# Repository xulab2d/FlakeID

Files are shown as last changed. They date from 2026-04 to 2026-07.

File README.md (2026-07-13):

# FlakeID

`flake-ml` is the starter software stack inside `FlakeID`, a research-backed framework for automated optical discovery of exfoliated 2D material flakes on a motorized microscope. It is designed around your current setup:

- Microscope: Zeiss AXIO Imager.A2m
- Motion: Arduino UNO + CNC shield running GRBL
- Camera: Canon DS126571 over USB
- Primary materials:
  - graphene on 285 nm Si/SiO2 (wet)
  - hBN on 90 nm Si/SiO2 (dry)

This repository focuses on the parts we can build immediately on the local workstation:

- serpentine scan planning
- GRBL integration hooks
- flat-field and background correction
- lightweight flake-candidate detection on CPU
- scan cataloging and COCO export for future training
- a practical data and human-in-the-loop plan

It also leaves clean interfaces for stronger models and remote training later.

## Repository Layout

- [docs/research_review.md](docs/research_review.md)
- [docs/system_architecture.md](docs/system_architecture.md)
- [docs/data_and_human_loop.md](docs/data_and_human_loop.md)
- [docs/bringup_checklist.md](docs/bringup_checklist.md)
- [docs/scanning_protocol.md](docs/scanning_protocol.md)
- [docs/stage_bounds_protocol.md](docs/stage_bounds_protocol.md)
- [docs/stage_calibration_ui.md](docs/stage_calibration_ui.md)
- [docs/camera_pathway.md](docs/camera_pathway.md)
- [docs/data_collection_workflow.md](docs/data_collection_workflow.md)
- [docs/drift_correction.md](docs/drift_correction.md)
- [docs/hardware_probe_notes.md](docs/hardware_probe_notes.md)
- [docs/repo_push_setup.md](docs/repo_push_setup.md)
- [configs/lab.example.toml](configs/lab.example.toml)
- [scripts/grbl_send.ps1](scripts/grbl_send.ps1)
- `src/flake_ml`: package code
- `tests`: lightweight regression tests

## Quick Start

Use the bundled Python runtime already available on this machine:

```powershell
& 'C:\Users\xulab\.cache\codex-runtimes\codex-primary-runtime\dependencies\python\python.exe' -m flake_ml.cli --help
```

Create a scan plan:

```powershell
& 'C:\Users\xulab\.cache\codex-runtimes\codex-primary-runtime\dependencies\python\python.exe' -m flake_ml.cli scan-plan `
  --config configs/lab.example.toml `
  --width-mm 8 `
  --height-mm 8 `
  --output outputs/scan_plan.json
```

Open the stage calibration UI:

```powershell
powershell.exe -NoProfile -ExecutionPolicy Bypass -File scripts\launch_stage_ui.ps1 `
  -Config configs/lab.example.toml
```

Run a capture scan over a saved scan ROI:

```powershell
& 'C:\Users\xulab\.cache\codex-runtimes\codex-primary-runtime\dependencies\python\python.exe' -m flake_ml.cli run-scan `
  --config configs/lab.example.toml `
  --sample-id graphene_grid_001 `
  --material graphene `
  --substrate graphene_285_wet `
  --objective 10x
```

Detect candidates in one image:

```powershell
& 'C:\Users\xulab\.cache\codex-runtimes\codex-primary-runtime\dependencies\python\python.exe' -m flake_ml.cli detect-image `
  path\to\image.jpg `
  --config configs/lab.example.toml `
  --output-json outputs\image_candidates.json `
  --overlay outputs\image_overlay.png
```

Probe the connected camera and installed Canon tooling:

```powershell
& 'C:\Users\xulab\.cache\codex-runtimes\codex-primary-runtime\dependencies\python\python.exe' -m flake_ml.cli camera-probe
```

Create a session scaffold for a new data-collection run:

```powershell
& 'C:\Users\xulab\.cache\codex-runtimes\codex-primary-runtime\dependencies\python\python.exe' -m flake_ml.cli init-session `
  --config configs/lab.example.toml `
  --output-root outputs\sessions `
  --sample-id graphene_trial_001 `
  --material graphene `
  --substrate graphene_285_wet `
  --objective 10x `
  --operator xulab
```

Estimate residual overlap shift between neighboring tiles:

```powershell
& 'C:\Users\xulab\.cache\codex-runtimes\codex-primary-runtime\dependencies\python\python.exe' -m flake_ml.cli estimate-shift `
  path\to\left_tile.jpg `
  path\to\right_tile.jpg `
  --axis x `
  --overlap-fraction 0.12
```

Score a z-stack or focus bracket with autofocus metrics:

```powershell
& 'C:\Users\xulab\.cache\codex-runtimes\codex-primary-runtime\dependencies\python\python.exe' -m flake_ml.cli focus-score `
  path\to\zminus.jpg `
  path\to\z0.jpg `
  path\to\zplus.jpg `
  --metric tenengrad `
  --crop-fraction 0.5
```

Replay a folder of microscope images into a catalog:

```powershell
& 'C:\Users\xulab\.cache\codex-runtimes\codex-primary-runtime\dependencies\python\python.exe' -m flake_ml.cli replay-folder `
  path\to\images `
  --config configs/lab.example.toml `
  --catalog outputs\flakes.db `
  --sample-id graphene_trial_001 `
  --material graphene
```

Export reviewed candidates to COCO:

```powershell
& 'C:\Users\xulab\.cache\codex-runtimes\codex-primary-runtime\dependencies\python\python.exe' -m flake_ml.cli export-coco `
  --catalog outputs\flakes.db `
  --output outputs\coco_candidates.json
```

Open the manual review UI for a scan session:

```powershell
& 'C:\Users\xulab\.cache\codex-runtimes\codex-primary-runtime\dependencies\python\python.exe' -m flake_ml.cli review-images `
  --session-dir photos\scans\20260424T024315Z_flake_grid_001
```

Launch the polygon-aware napari reviewer for precise flake boundaries:

```powershell
powershell.exe -NoProfile -ExecutionPolicy Bypass -File scripts\launch_napari_review.ps1 `
  -SessionDir photos\scans\20260424T024315Z_flake_grid_001
```

Use napari polygon mode for irregular flake outlines and rectangle mode only for quick coarse labels. The napari reviewer saves polygon vertices directly into the same `manual_annotations.json` file, so later COCO exports keep the real outline instead of collapsing everything to crude boxes.

Recommended tile labels:

- `flake_present`: the field contains one or more flakes worth annotating
- `empty_substrate`: true negative on the correct substrate with no flake present
- `off_target`: the stage is between sites or otherwise not over a useful survey location
- `bad_focus`: the field is not trustworthy because focus failed
- `artifact`: dust, glare, tape residue, edge effects, or other nuisance structure
- `unsure`: reviewer cannot confidently decide yet

Object labels stay flake-specific: `graphene`, `hbn`, `other_flake`, and `artifact`.

The napari reviewer also supports object-level metadata for downstream ranking:

- `thickness_bin`: `unknown`, `mono`, `bi`, `few_layer`, `thick`
- `size_class`: `unknown`, `tiny`, `small`, `usable`, `large`
- `shape_class`: `unknown`, `bottom_gate_candidate`, `channel_candidate`, `irregular`, `fragmented`
- `priority`: `unknown`, `ignore`, `review`, `device_candidate`

Set those in the dock and click `Apply Metadata To Selected` after selecting one or more flakes.

Reviewer navigation tips:

- reopening the same session resumes at the most recently saved image
- type an image number or filename fragment in the jump box and press `Enter`
- `[` and `]` move backward and forward
- `Ctrl+L` focuses the jump box
- `Ctrl+G` jumps to the typed image
- `Ctrl+J` jumps back to the saved resume target

Export manual review polygons or boxes to COCO:

```powershell
& 'C:\Users\xulab\.cache\codex-runtimes\codex-primary-runtime\dependencies\python\python.exe' -m flake_ml.cli export-manual-coco `
  --review-path photos\scans\20260424T024315Z_flake_grid_001\labels\manual_annotations.json `
  --output outputs\manual_annotations.coco.json
```

## Photo Storage

- `photos/incoming`: fallback hot folder for EOS Utility download handoff
- `photos/scans/<timestamp>_<sample_id>`: one folder per scan with tiles, logs, QC, and catalog files
- `photos/scans/<timestamp>_<sample_id>/labels/manual_annotations.json`: manual flake review output from the Tk reviewer or the napari polygon reviewer

The `photos/` tree is gitignored.

## Direct Canon Capture

The preferred camera path on this workstation is now the local Canon SDK helper:

```powershell
powershell.exe -NoProfile -ExecutionPolicy Bypass -File scripts\canon_sdk_capture.ps1 -Probe
```

For a direct still-image test:

```powershell
powershell.exe -NoProfile -ExecutionPolicy Bypass -File scripts\canon_sdk_capture.ps1 `
  -Output outputs\camera_test.jpg
```

Close `EOS Utility` or any Canon live-view window before using the direct SDK path, because the camera session is exclusive.

## What This Does Not Yet Solve

- autofocus for Z
- robust multilayer thickness regression
- remote model training orchestration
- scan-time stitch mosaics

Those are all outlined in the docs as the next build stages.

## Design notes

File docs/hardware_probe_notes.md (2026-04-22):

# Hardware Probe Notes

Date: `2026-04-22`

These notes were collected directly from the microscope control computer without moving the stage.

## GRBL Reachability

- `COM3` responds as `Grbl 0.9j`
- a status probe returned:
  - `<Idle,MPos:0.000,0.000,0.000,WPos:-1.050,-3.000,0.000>`

This means the Arduino/GRBL side is reachable from the workstation.

## Reported GRBL Settings

- `$100=250.000` x steps/mm
- `$101=250.000` y steps/mm
- `$102=250.000` z steps/mm
- `$110=200.000` x max rate mm/min
- `$111=500.000` y max rate mm/min
- `$112=500.000` z max rate mm/min
- `$120=10.000` x accel mm/s^2
- `$121=10.000` y accel mm/s^2
- `$122=10.000` z accel mm/s^2
- `$130=200.000` x max travel mm
- `$131=200.000` y max travel mm
- `$132=200.000` z max travel mm

## Immediate Implications

- GRBL coordinates are in `mm`, so the software layer should expose microns internally but convert to millimeters at the hardware boundary.
- The current default travel rate in the config, `2500 um/s`, corresponds to `150 mm/min`, which is under the current x-axis max rate of `200 mm/min`.
- Early scan tests should stay comfortably below the configured x-axis maximum until real motion is validated on the microscope.

## Recommended Next Hardware Test

1. Unlock GRBL if needed.
2. Jog `50 um` in `+X`, then return.
3. Jog `50 um` in `+Y`, then return.
4. Confirm the microscope image motion matches the expected axis signs.
5. Only then attempt a `3 x 3` image overlap test.

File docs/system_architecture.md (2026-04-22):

# System Architecture

## Goal

Turn a motorized optical microscope into a reliable flake-scanning instrument that can:

1. move reproducibly across a sample,
2. capture tiles with stable metadata,
3. detect likely flakes,
4. rank them for review or revisits,
5. accumulate training data for stronger models.

## Architecture

### 1. Motion Layer

Responsibilities:

- connect to GRBL on the Arduino UNO
- home and unlock safely
- move to absolute XY positions
- wait for idle before capture

Implementation in this repository:

- `flake_ml.motion.base.MotionController`
- `flake_ml.motion.grbl.PowerShellGrblController`
- `flake_ml.motion.pyserial_grbl.PySerialGrblController`
- `scripts/grbl_send.ps1`

Why this design:

- `pyserial` is not guaranteed on this machine, but PowerShell can access `System.IO.Ports.SerialPort` directly on Windows.
- The PowerShell path is useful for probing or one-off diagnostics.
- Real automated scanning should use the persistent `PySerialGrblController`, because reopening the serial port can reset an Arduino UNO running GRBL.

## 2. Camera Layer

Responsibilities:

- trigger a capture
- save the image to a known path
- attach tile metadata

Implementation in this repository:

- `flake_ml.acquisition.base.Camera`
- `flake_ml.acquisition.command.ExternalCommandCamera`
- `flake_ml.acquisition.command.DirectoryReplayCamera`

Why this design:

- Canon tethering is the least stable part of the current setup because the exact Windows-side control path is still unknown.
- An external command interface lets you plug in EOS Utility, Canon SDK tooling, `gphoto2`, or any future wrapper without touching the rest of the pipeline.

## 3. Scan Planner

Responsibilities:

- convert sample bounds and field of view into a tile grid
- use a serpentine path to reduce wasted stage travel
- preserve stage coordinates for every image

Implementation:

- `flake_ml.scanning.planner.build_serpentine_plan`

## 4. Preprocessing

Responsibilities:

- flat-field correction
- white-balance normalization
- slow-varying background estimation
- stable inputs for classical and learned detectors

Implementation:

- `flake_ml.processing.preprocess`

## 5. Detection

Responsibilities:

- generate conservative candidate regions from a tile
- score candidates for review
- compute features for later clustering or learning

Implementation:

- `flake_ml.detection.classical.ClassicalFlakeDetector`
- `flake_ml.detection.components`
- `flake_ml.processing.features`

Current algorithm:

- estimate background by downsampling and re-expanding the image
- measure robust color/saturation/luminance deviations
- build a candidate mask
- clean it with simple morphology
- run connected components
- compute component statistics
- assign heuristic scores

Why this first:

- It is fast on CPU.
- It gives you useful candidates before you have training data.
- It produces structured features that can seed later GMM or supervised models.

## 6. Catalog

Responsibilities:

- store scans, tiles, and candidates
- track review labels
- export training data

Implementation:

- `flake_ml.catalog.CatalogStore`

Database:

- SQLite via the Python standard library

Stored objects:

- scans
- tiles
- candidates

## 7. Learning Layer

Responsibilities:

- weakly supervised clustering of candidate appearance
- binary acceptance ranking from reviewed examples

Implementation:

- `flake_ml.learning.gmm.GaussianMixtureModel`
- `flake_ml.learning.logistic.LogisticRegressor`

Why this matters:

- It gives you a useful middle layer between pure heuristics and a full deep network.
- It is appropriate for the small-data phase.

## 8. Annotation Export

Responsibilities:

- turn reviewed candidates into standard training formats

Implementation:

- `flake_ml.annotation.coco.export_catalog_to_coco`

Why COCO:

- most segmentation/detection toolchains can consume it directly or convert from it easily
- it keeps the path open to Mask R-CNN, Detectron2, MaskTerial, or other modern stacks

## Recommended Deployment Stages

### Stage 0

- wire hardware
- confirm GRBL communication
- confirm reproducible field of view

### Stage 1

- run folder replay on existing microscope images
- tune candidate thresholds
- validate catalog and review flow

### Stage 2

- live XY scanning
- save every tile with stage coordinates
- human review loop for accepted/rejected candidates

### Stage 3

- fit GMM or simple acceptance model
- prioritize likely flakes instead of all candidates equally

### Stage 4

- train or fine-tune segmentation on cluster/GPU machine
- deploy the compact inference model back to the microscope PC

### Stage 5

- add autofocus and revisit logic
- optionally add active search policies or contextual bandits

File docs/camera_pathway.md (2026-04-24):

# Camera Pathway

## What We Confirmed On This Workstation

From a direct probe on `2026-04-23`:

- the camera enumerates in Windows as `Canon EOS Rebel T6i`
- `EOS Utility 3` is installed locally at `C:\Program Files (x86)\Canon\EOS Utility\EU3\EOS Utility 3.exe`
- Canon `EDSDK.dll` is installed locally at `C:\Program Files (x86)\Canon\EOS Utility\EU3\EDSDK.dll`
- the local EDSDK version is `3.17.0.1`
- the local EOS Utility version is `3.18.5.13`
- the Windows WIA path only exposes `Synchronize`, not `Take Picture`

Bottom line:

- the long-term automation path should be Canon `EDSDK` over USB
- the near-term practical bridge is `EOS Utility` saving into a watched folder
- WIA is only a diagnostic/import fallback on this camera

## Recommended Capture Stack

### Stage A: Direct SDK Capture

Use the repo helper around Canon `EDSDK.dll`:

```powershell
powershell.exe -NoProfile -ExecutionPolicy Bypass -File scripts\canon_sdk_capture.ps1 -Probe
```

And for a real shutter test:

```powershell
powershell.exe -NoProfile -ExecutionPolicy Bypass -File scripts\canon_sdk_capture.ps1 `
  -Output outputs\camera_test.jpg
```

This helper:

- opens one Canon session directly through `EDSDK.dll`
- switches the save destination to the host PC
- triggers the shutter
- downloads the captured image to the requested path

Important:

- close `EOS Utility` and any live-view window before running it
- Canon camera sessions are exclusive, so the SDK helper cannot open the body while EOS Utility still owns it

### Stage B: Watched-Folder Fallback

If direct SDK capture is temporarily unavailable, FlakeID can still fall back to `EOS Utility` plus a watched hot folder at `photos/incoming`.

### Stage C: Optional Live-View Integration

After still-image capture is stable, add optional live-view support for:

- focus checks
- brightness checks
- anchor alignment checks before longer scans

Do not make live view a blocker for tile capture.

## Camera Settings To Lock

For early dataset collection, keep the camera configuration fixed within a workflow:

- manual exposure mode
- fixed shutter speed
- fixed ISO
- fixed white balance
- fixed image quality
- fixed picture style
- disable auto lighting optimizer
- disable highlight tone priority
- disable long-exposure noise reduction
- disable high-ISO noise reduction
- disable lens corrections or any other scene-dependent processing

If storage is acceptable, prefer `RAW+JPEG` on the camera while ingesting `JPEG` into the current pipeline. That preserves raw data for future color/thickness calibration without blocking the current software.

## Why Not WIA

Windows WIA is useful only as a sanity check here. On this T6i probe, WIA exposed only `Synchronize` and did not expose `Take Picture`, so it should not be treated as the automation path.

## Repo Commands

Probe the camera environment:

```powershell
& 'C:\Users\xulab\.cache\codex-runtimes\codex-primary-runtime\dependencies\python\python.exe' -m flake_ml.cli camera-probe
```

Create a new session scaffold:

```powershell
& 'C:\Users\xulab\.cache\codex-runtimes\codex-primary-runtime\dependencies\python\python.exe' -m flake_ml.cli init-session `
  --config configs/lab.example.toml `
  --output-root outputs/sessions `
  --sample-id graphene_trial_001 `
  --material graphene `
  --substrate graphene_285_wet `
  --objective 10x `
  --operator xulab
```

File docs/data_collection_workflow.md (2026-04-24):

# Data Collection Workflow

## Goal

Collect microscope images in a way that is immediately usable for:

- candidate detection
- manual review
- later re-registration and drift correction
- later supervised training

## Scan Folder Layout

Each automated raster now creates its own folder inside `photos/scans`.

A typical scan folder contains:

- `tiles`: curated per-tile images used by the pipeline
- `blankfield`: blank substrate or no-sample images for flat-field correction
- `anchors`: reference images used for drift / backlash checks
- `labels`: exported annotations or review artifacts
- `logs`: acquisition logs and notes
- `qc`: scan plan, summaries, and registration diagnostics
- `scan_catalog.db`: SQLite catalog for the scan

The fixed EOS Utility hot folder should be:

- `photos/incoming`

This avoids changing the EOS Utility save destination for every scan. FlakeID watches that one folder and copies each new image into the active scan folder automatically.

## Start-Of-Scan Checklist

1. Run `camera-probe` once and confirm the expected camera is present.
2. In EOS Utility, point downloads to `photos/incoming`.
3. Lock microscope lamp intensity and camera settings.
4. Confirm the current objective and sample metadata in the scan UI.
5. Mark the scan ROI edges, then start with a small pilot raster before larger runs.

## Capture Order

### 1. Blank Fields

Collect `20-30` blank-field images at the beginning of the session.

Use:

- same objective
- same lamp setting
- same camera settings
- representative substrate region with no obvious flakes

Repeat another `10-20` blank fields at the end of the session if the session is long.

### 2. Anchor Images

Before the first scan, capture anchor images from one or more fixed reference locations.

Good anchor targets:

- a scribed edge mark on the wafer perimeter
- a fixed reference chip mounted at the holder edge
- a stable dust/scratch cluster near a non-critical corner if nothing better exists

Capture anchors:

- before the scan
- every few rows or every few millimeters during longer scans
- after the scan

### 3. Pilot Tiles

Collect a small pilot area first:

- `3 x 3` or `5 x 5` tiles
- same overlap you plan to use for production
- verify focus, brightness, and overlap consistency

### 4. Production Tiles

Once the pilot looks stable, acquire the larger raster.

## If Capture Triggering Is Still Manual

If `camera.capture_command` is blank and the driver is `watched_folder`, the scan waits at each tile until a new image appears in `photos/incoming`.

That is still useful for:

- early camera bring-up
- testing raster geometry
- small human-supervised pilot scans

Once a direct trigger command or Canon SDK helper is added, the same scan folders and UI workflow continue to work.

## Labeling Priorities

Start with the highest-value labels first:

1. tile-level `usable / not usable`
2. candidate-level `flake / not flake`
3. material label `graphene / hBN / other`
4. quality label `interesting / ignore / revisit`

Thickness labels can come later, after the acquisition pipeline is stable.

## File Naming Guidance

Each tile filename should eventually encode:

- session id
- tile row / column
- stage coordinates
- timestamp
- material / substrate context if needed

This keeps later registration, relabeling, and model training much easier.

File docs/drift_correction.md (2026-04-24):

# Drift And Backlash Correction

## What The Current Mechanics Suggest

The belt slack looks more like backlash and direction-dependent hysteresis than steady monotonic drift.

That usually means:

- moves in the same direction are fairly repeatable
- reversals are worse
- a pure serpentine scan can accumulate row-to-row registration changes even if the stage does not truly drift away

## Immediate Software Mitigations

### 1. Prefer Same-Direction Final Approach

When possible, approach the final imaging coordinate from the same direction each time.

Two practical ways:

- use a flyback raster instead of a pure serpentine raster
- overshoot and settle back to the target by a calibrated backlash amount

### 2. Measure Backlash From Images

Use overlapping tiles or anchor revisits to estimate the actual residual shift.

The repo now includes:

```powershell
& 'C:\Users\xulab\.cache\codex-runtimes\codex-primary-runtime\dependencies\python\python.exe' -m flake_ml.cli estimate-shift `
  path\to\left_tile.jpg `
  path\to\right_tile.jpg `
  --axis x `
  --overlap-fraction 0.12
```

This measures the pixel shift inside the overlapping region and is a good first tool for quantifying backlash.

### 3. Periodic Anchor Re-Registration

For longer scans, revisit a known anchor location every few rows or every few millimeters.

If the anchor image shifts relative to the original anchor:

- update the stage-to-image coordinate model
- or at minimum flag that part of the scan for correction / reacquisition

## Fiducial Strategies That Do Not Pollute The Sample Area

Good options:

- a tiny scribed mark on a sacrificial wafer edge
- a permanent reference chip fixed to the sample holder outside the scan ROI
- a corner reference slide or etched marker mounted on the carrier

Avoid putting fiducials in the actual flake-search region.

## Recommended Progression

1. quantify X and Y backlash from overlap images
2. decide whether flyback or backlash-compensated serpentine is better
3. add anchor revisits every `5-10` rows for larger scans
4. only after that invest in more complex mosaic correction

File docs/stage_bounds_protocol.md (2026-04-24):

# Stage Bounds Protocol

## Short Answer

Yes, manual knob motion can help you define the stage bounds for this session.

But no, GRBL will not reliably register that manual motion.

Your current setup is open-loop:

- Arduino UNO
- CNC shield
- GRBL `0.9j`
- no encoder feedback
- homing and soft limits currently disabled

That means GRBL only knows about moves it commanded itself. If you turn the knobs by hand, the controller position becomes untrusted until you re-zero or re-home.

## Important Detail From Today's Probe

On `2026-04-22`, the machine reported:

- `$21=0` hard limits off
- `$22=0` homing off
- `$1=2` step idle delay 2 ms

So the motors release quickly when idle, which means gentle manual turning is probably fine mechanically when the stage is not moving. But the controller still does not "see" the motion.

## Recommended Strategy

Use manual motion only to place the stage at a known physical corner.

Then tell GRBL that this location is your working origin.

After that, use **commanded positive moves only** to map the safe `+X` and `+Y` travel.

Do not discover limits by commanding the motors into the hard stops.

## Safe Procedure

### 1. Start at the lower-left corner by hand

Since you believe the stage is already at minimum `X` and minimum `Y`:

1. Gently confirm that you are really at the lower-left mechanical corner.
2. Back off slightly from the hard stop by hand, about `0.2 mm` to `0.5 mm`.
3. From this point forward, treat that backed-off location as the true session origin.

Why back off:

- avoids riding the belts against the stop
- avoids starting a scan with preload already in the mechanics

## 2. Re-register the controller at this corner

After any manual movement, query status and then set the work origin:

```powershell
powershell.exe -NoProfile -ExecutionPolicy Bypass -File scripts\grbl_send.ps1 `
  -Port COM3 -Baud 115200 -StartupDelayMs 2000 `
  -Command ? -WaitFor '<' -TimeoutMs 4000
```

Then set the current position to work `X=0`, `Y=0`:

```powershell
powershell.exe -NoProfile -ExecutionPolicy Bypass -File scripts\grbl_send.ps1 `
  -Port COM3 -Baud 115200 -StartupDelayMs 2000 `
  -Command 'G92 X0 Y0' -WaitFor ok -TimeoutMs 4000
```

If you manually move again after this, repeat the zeroing step.

## 3. Verify axis signs with tiny jogs

Use very small commanded moves first:

```powershell
powershell.exe -NoProfile -ExecutionPolicy Bypass -File scripts\grbl_send.ps1 `
  -Port COM3 -Baud 115200 -StartupDelayMs 2000 `
  -Command 'G21','G91','G0 X0.05 F60' -WaitFor ok -TimeoutMs 4000
```

That is:

- `G21` millimeters
- `G91` relative mode
- `X0.05` = `50 um`
- `F60` = `60 mm/min`

Do the same for `-X`, `+Y`, and `-Y`, returning to the origin after each test. Confirm the microscope image motion and the stage motion match your expectations.

## 4. Map the safe positive X bound

Once signs are confirmed:

1. Move in `+X` using `1 mm` steps through the interior.
2. When you are within about `5 mm` of the end, switch to `0.2 mm` or `0.5 mm` steps.
3. Stop before any belt tension spike or hard-stop contact.
4. Back off by `0.5 mm` to `1.0 mm`.
5. Record that location as `X_MAX_SAFE`.

Example relative jog:

```powershell
powershell.exe -NoProfile -ExecutionPolicy Bypass -File scripts\grbl_send.ps1 `
  -Port COM3 -Baud 115200 -StartupDelayMs 2000 `
  -Command 'G21','G91','G0 X1.0 F120' -WaitFor ok -TimeoutMs 4000
```

## 5. Return to origin and map Y the same way

Repeat the same process for `+Y`:

- coarse `1 mm` steps first
- fine `0.2 mm` to `0.5 mm` steps near the edge
- back off `0.5 mm` to `1.0 mm`
- record `Y_MAX_SAFE`

## 6. Use a safety inset, not the raw measured maximum

Once you have the farthest safe visible locations:

- define `safe_min_x = 0`
- define `safe_min_y = 0`
- define `safe_max_x = measured_x_max - 500 um to 1000 um`
- define `safe_max_y = measured_y_max - 500 um to 1000 um`

Those inset values are what should go into the config.

## 7. Save the results in the config

Update [configs/lab.example.toml](../configs/lab.example.toml) or your real lab config:

```toml
[motion]
min_x_um = 0.0
min_y_um = 0.0
max_x_um = 123400.0
max_y_um = 98700.0
safety_margin_um = 1000.0
```

The scan planner will then refuse plans that exceed the configured safe envelope.

## What Manual Motion Is Good For

- placing the stage at a known corner before zeroing
- gently confirming where the physical stops are
- recovering after you intentionally reposition by hand

## What Manual Motion Is Not Good For

- expecting GRBL coordinates to update automatically
- mixing manual and motorized moves without re-zeroing
- defining a trustworthy absolute coordinate system for future sessions

## Best Long-Term Fix

Add real homing switches.

Once homing is enabled:

- you can home at startup
- machine coordinates become repeatable
- soft limits become meaningful
- accidental belt grinding risk drops sharply

Until then, use session-local work coordinates and a conservative safety inset.

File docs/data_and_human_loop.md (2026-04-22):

# Data And Human Loop

## Short Answer

You do not need reinforcement learning to get this system off the ground.

What you need first is:

- calibration data,
- tile-level scan data,
- candidate-level human labels,
- a small number of high-confidence flake exemplars.

Reinforcement learning only becomes useful later, after the microscope can already detect and rank flakes reliably.

## Data You Need In The First Month

### 1. Background And Calibration Images

Collect for each material workflow and each commonly used objective:

- 30 to 50 blank-substrate images with no flakes
- 10 to 20 images at each exposure setting you may actually use
- 10 to 20 images at the beginning and end of a session to quantify drift

Why:

- build flat-field correction
- estimate background color statistics
- quantify lamp and white-balance variation

## 2. Real Scan Tiles

Collect full scans, not just cropped flakes:

- at least 20 whole-slide or partial-slide scans per substrate/material workflow
- include easy, hard, clean, dirty, sparse, and residue-heavy samples

Why:

- discovery systems fail on the negative space if they only ever see curated positives
- real scan statistics matter for false-positive control

## 3. Candidate Review Labels

For each detected candidate, a reviewer should ideally assign:

- `accept`
- `reject`
- `ambiguous`

Optional but high-value tags:

- `graphene`
- `hbn`
- `few_layer`
- `thick`
- `folded`
- `cracked`
- `tape_residue`
- `contaminated`
- `good_for_transfer`

Bootstrap target:

- 200 to 500 reviewed candidates per workflow is enough to start improving ranking
- 1000 to 2000 reviewed candidates makes a serious phase-two model realistic

## 4. Thickness-Oriented Labels

If you care about monolayer or few-layer prioritization, also collect:

- 50 to 100 confirmed examples per thickness bin you care about
- Raman/AFM confirmation for a smaller gold-standard subset

Why:

- optical appearance is correlated with thickness, but camera and illumination confound it
- even a small confirmed set is enough to calibrate cluster meanings

## 5. Focus Data For Autofocus

When you add Z:

- capture focus stacks at representative sample locations
- save the true best-focus index chosen by a human

Why:

- autofocus becomes much easier if you treat it as a supervised ranking problem over local Z stacks

## The Right Human Loop

### Phase 1

Human reviews every surfaced candidate.

Goal:

- high recall
- learn the lab's nuisance modes

### Phase 2

Human reviews only the top-scoring or uncertain candidates.

Goal:

- active learning
- reduce annotation load while improving the model

### Phase 3

Human mostly validates the best-ranked flakes and inspects unusual failures.

Goal:

- turn the system into a trustworthy assistant rather than a noisy generator of boxes

## Where RL Actually Fits

Use RL only after the basics work.

The first worthwhile RL-like problems are usually contextual-bandit problems, not full reinforcement learning:

- which tile should be rescanned at higher magnification?
- which candidate should be surfaced to a human first?
- which scan regions are worth revisiting after coarse screening?

Possible rewards:

- reviewer accepted candidate
- confirmed monolayer or target-thickness discovery
- successful transfer or device fabrication outcome

That is much later than basic flake discovery.

## Practical Labeling Guidance

Keep the first review interface minimal:

- single hotkey for `accept`
- single hotkey for `reject`
- single hotkey for `ambiguous`
- optional tag panel only when needed

If you make reviewers answer ten questions per candidate, the dataset will stall out.

## Suggested Dataset Targets

### Minimum viable

- 20 scans per workflow
- 300 reviewed candidates per workflow
- 50 confirmed positives per workflow

### Strong phase-two training set

- 50 to 100 scans per workflow
- 1500 or more reviewed candidates per workflow
- 200 or more confirmed positive flakes per workflow
- 100 or more gold-standard thickness labels across bins

## Validation Metrics That Matter

- recall of human-accepted flakes
- false positives per square millimeter scanned
- time-to-first-good-flake
- precision among top `k` ranked candidates
- consistency across days and lamp conditions

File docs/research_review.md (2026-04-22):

# Research Review

## Bottom Line

The literature now supports a practical staged strategy for your microscope:

1. Start with physically informed preprocessing plus classical candidate generation.
2. Use lightweight human review to build a lab-specific dataset.
3. Fine-tune a modern detection/segmentation model on a stronger GPU only after the data pipeline is stable.
4. Keep local inference lightweight enough that scan-time ranking can still happen on the microscope PC.

That path matches both the hardware you have now and the strongest published systems.

## Key Papers And What They Mean For You

### 1. Autonomous microscope search and assembly is already proven

Masubuchi et al. demonstrated automated search and pickup for exfoliated 2D crystals with a robotic microscope platform, showing that autonomous optical discovery is realistic rather than speculative:

- T. Masubuchi et al., "Autonomous robotic searching and assembly of two-dimensional crystals to build van der Waals superlattices", *Nature Communications* 9, 1413 (2018).
- Link: [nature.com](https://www.nature.com/articles/s41467-018-03806-x)

Why it matters here:

- The hard problem is not only detection accuracy; it is integrating motion, image analysis, and sample bookkeeping.
- Their work validates building the microscope stack first instead of waiting for a perfect model.

### 2. Illumination-robust deep segmentation works well for 2D materials

Masubuchi et al. later reported deep-learning image segmentation for automatically searching 2D materials in optical microscope images:

- T. Masubuchi et al., "Deep-learning-based image segmentation integrated with optical microscopy for automatically searching for two-dimensional materials", *npj 2D Materials and Applications* 4, 9 (2020).
- Link: [nature.com](https://www.nature.com/articles/s41699-020-0137-z)

Why it matters here:

- They explicitly targeted robustness to illumination/color-balance variation, which is one of the biggest real failure modes in flake labs.
- This supports collecting your own flat-field and background calibration data from day one.
- Their approach is a strong phase-two destination once enough labeled local data exists.

### 3. Large-scale unlabeled graphene scans already support unsupervised layer clustering

Masubuchi and Machida also showed that large optical scan collections can be mined without dense manual labels:

- S. Masubuchi and T. Machida, "Classifying optical microscope images of exfoliated graphene flakes by data-driven machine learning", *npj 2D Materials and Applications* 3, 4 (2019).
- Link: [nature.com](https://www.nature.com/articles/s41699-018-0084-0)

Why it matters here:

- They processed about 70,000 microscope images and extracted about 400,000 segmented regions.
- Unsupervised clustering in optical feature space classified mono-, bi-, and trilayer graphene with reported accuracy above 95%.
- This is a very strong precedent for using weak supervision and GMM-like models in your graphene-on-285 nm workflow.

### 4. Small-data segmentation is possible, but setup quality matters

Saito et al. showed U-Net-based detection of graphene and MoS2 flakes using a very small number of training images:

- Y. Saito et al., "Automated identification of exfoliated 2D materials using machine learning-based image segmentation", *Applied Physics Express* 12, 095001 (2019).
- Link: [iopscience.iop.org](https://iopscience.iop.org/article/10.7567/1882-0786/ab37f0)

Why it matters here:

- Your first model does not need thousands of labeled scans.
- But small-data learning only works if the microscope acquisition is consistent enough that the model is not fighting drift in lamp spectrum, exposure, white balance, or focus.

### 5. Universal or weakly supervised pixel models can reduce annotation cost

Sterbentz et al. proposed a Gaussian-mixture based system that can classify pixels of 2D materials with very little user supervision:

- J. Sterbentz et al., "Universal image segmentation for optical identification of two-dimensional materials", *Scientific Reports* 11, 16565 (2021).
- Link: [nature.com](https://www.nature.com/articles/s41598-021-96072-w)

Why it matters here:

- This is a good match for your near-term needs because it can bootstrap from color/contrast structure before you have a large segmentation dataset.
- It also motivates the GMM-based clustering module included in this repository.

### 6. Physics-informed learning is especially attractive when data is limited

Zichi et al. compared physics-aware machine-learning approaches for optical identification of 2D crystals:

- J. Zichi et al., "Physically informed machine-learning algorithms for the identification of two-dimensional atomic crystals", *Scientific Reports* 13, 5902 (2023).
- Link: [nature.com](https://www.nature.com/articles/s41598-023-33298-6)

Why it matters here:

- They found strong performance from tree-based and physically informed models with limited training data.
- For your lab, that argues against jumping straight to a large end-to-end model before exploiting substrate-aware optical priors.

### 7. Dedicated hBN computer vision is now emerging

Ramezani et al. reported automated multilayer hBN detection from optical images:

- M. Ramezani et al., "Automatic detection of multilayer hexagonal boron nitride in optical images using deep learning-based computer vision", *Scientific Reports* 13, 13387 (2023).
- Link: [nature.com](https://www.nature.com/articles/s41598-023-40039-8)

Why it matters here:

- hBN is no longer an afterthought in the literature.
- Your hBN-on-90 nm workflow is worth treating as a first-class target rather than forcing a graphene-only pipeline to generalize later.

### 8. Recent open implementations reduce the barrier to real deployment

Two recent systems are especially relevant:

- J. Lutz et al., "An open-source robust machine learning platform for real-time detection and classification of 2D material flakes", *Machine Learning: Science and Technology* 5, 015027 (2024).
- Paper link: [iopscience.iop.org](https://iopscience.iop.org/article/10.1088/2632-2153/ad2287)
- Code link: [github.com/Jaluus/2DMatGMM](https://github.com/Jaluus/2DMatGMM)

- A. de Ruiter et al., "MaskTerial: A synthetic image training framework for machine learning based detection and segmentation of atomic thin materials on low-contrast substrates", *Machine Learning: Science and Technology* 6, 035065 (2025).
- Paper link: [iopscience.iop.org](https://iopscience.iop.org/article/10.1088/2632-2153/adfc93)
- Code link: [github.com/atomstocondensates/MaskTerial](https://github.com/atomstocondensates/MaskTerial)

Why they matter here:

- `2DMatGMM` emphasizes practical, open, real-time detection on commodity hardware.
- `MaskTerial` is attractive for low-contrast substrates and small-data adaptation because it uses synthetic pretraining.
- `2DMatGMM` specifically reports real-time detection on a standard laptop without a GPU in its public code documentation.
- `MaskTerial` reports that synthetic pretraining can make 2 to 10 example images per class surprisingly useful, especially for low-contrast hBN.
- Together, they suggest that local CPU inference may be enough for screening even if training happens elsewhere.

### 9. Foundation-style autonomous microscopy is arriving, but it is not your first step

Li et al. introduced a zero-shot autonomous microscopy framework for 2D materials:

- Y. Li et al., "Zero-Shot Autonomous Microscopy for Scalable and Intelligent Characterization of 2D Materials", *ACS Nano* 19, 15148-15159 (2025).
- Link: [pubs.acs.org](https://pubs.acs.org/doi/10.1021/acsnano.5c09057)

Why it matters here:

- The field is moving toward foundation-model-guided microscopy.
- But these systems still depend on disciplined acquisition, calibration, and scan orchestration.
- For your microscope, this is a future upgrade path rather than the right starting point.

## Substrate-Specific Implications

### Graphene on 285 nm Si/SiO2

This remains one of the best-established optical-contrast systems in the literature:

- P. Blake et al., "Making graphene visible", *Applied Physics Letters* 91, 063124 (2007).
- Link: [aip.scitation.org](https://pubs.aip.org/aip/apl/article/91/6/063124/927198/Making-graphene-visible)

Implications:

- Classical contrast-based detection should work well once you normalize illumination.
- Thickness estimation can often begin with color/contrast clustering before full supervised learning.

### hBN on 90 nm Si/SiO2

Thin hBN is also optically discoverable on oxide, with substrate thickness strongly affecting visibility:

- R. V. Gorbachev et al., "Hunting for monolayer boron nitride: optical and Raman signatures", *Small* 7, 465-468 (2011).
- Link: [onlinelibrary.wiley.com](https://onlinelibrary.wiley.com/doi/10.1002/smll.201001628)

Implications:

- 90 nm oxide is a good choice for optical hBN discovery.
- Exact color thresholds remain microscope-specific, so local calibration images are still required.

## Practical Recommendation

### What to build first

- Stable scan planning and tile bookkeeping
- Flat-field correction
- Candidate generation with conservative thresholds
- Human review queue and annotation export

### What to defer

- End-to-end reinforcement learning
- Fully autonomous transfer or pick-and-place
- A large segmentation model trained before the data pipeline exists

### Where remote GPUs help most

- fine-tuning segmentation models
- synthetic data generation and ablations
- large hyperparameter sweeps

### Where the local microscope PC is likely enough

- stage control
- image capture orchestration
- background correction
- heuristic or GMM-based candidate ranking
- running a compact trained detector for inference

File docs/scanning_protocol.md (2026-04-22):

# Scanning Protocol v0.1

## Goal

Get a stable, labelable first dataset for flake discovery before motorized focus exists.

This protocol is deliberately conservative. It prioritizes repeatability over area throughput.

## Core Decision

For the first phase, use a **single fixed objective**, **single fixed illumination recipe**, and **small flat scan windows**.

My recommendation is:

- coarse automated discovery at `10x`
- optional manual revisit of good candidates at `20x` or higher
- no objective changes during a data-collection session

If your available objective set makes `10x` impractical, `20x` is the backup, but then the scan area per session should be smaller until XY and focus stability are proven.

## Why This Protocol First

- No motorized Z means focus variation is the main bottleneck.
- Changing objectives early multiplies calibration burden.
- Small, repeatable scans produce better training data than large inconsistent scans.
- Graphene on 285 nm oxide and hBN on 90 nm oxide both benefit from tightly controlled optical conditions.

## Recommended Bootstrap Protocol

### Session setup

1. Warm up the illumination source for a fixed amount of time.
2. Use one objective only for the full session.
3. Lock camera exposure, ISO, white balance, and file format.
4. Keep condenser/aperture settings unchanged for the whole session.
5. Record substrate, oxide thickness, sample prep, objective, and exposure in the session metadata.

### Before the first scan

1. Capture `20 to 30` blank-field images on clean bare substrate.
2. Capture `5` repeat blank fields after refocusing to estimate session variance.
3. Focus at the center of the intended ROI.
4. Check focus at the four corners of that ROI.

### ROI size

Until motorized focus exists, start with:

- `2 mm x 2 mm` automated scans at `10x`
- if the sample is very flat and all corners stay acceptably sharp, increase to `3 mm x 3 mm`
- avoid larger windows at first

At `20x`, start smaller:

- `1 mm x 1 mm` to `1.5 mm x 1.5 mm`

## Motion And Imaging Settings

### XY path

- serpentine raster
- overlap: `12%`
- stage settle time after each move: `250 to 400 ms`

### Focus strategy without motorized Z

- choose the focus plane that best preserves flake edges across the whole ROI, not just at the center
- if corners visibly drift out of focus, shrink the scan window rather than forcing a bigger scan
- keep the sample orientation fixed during a session

### Capture order

For each sample:

1. blank-field calibration
2. one or two small pilot scans
3. review pilot scan for overlap and focus consistency
4. only then run additional scans

## Substrate-Specific Notes

### Graphene on 285 nm wet Si/SiO2

- This should be the easiest of your two workflows to bootstrap.
- Favor getting high-quality negative space and contamination examples, not just obvious flakes.
- Early ranking can focus on mono/few-layer-like color deviations plus compact polygonal shapes.

### hBN on 90 nm dry Si/SiO2

- Keep illumination especially stable because thin hBN can be subtle.
- Collect more blank-field images per session than you think you need.
- Plan on more human review per square millimeter than graphene in the early phase.

## First Bench Test

### Test 1: communication only

- confirm GRBL responds on the expected COM port
- do not move the stage yet

### Test 2: tiny motion square

- move a very small square path near the current location
- confirm commanded direction signs match microscope motion
- confirm no cable snag or backlash surprise

Suggested first motion amplitudes:

- `50 um`
- then `100 um`
- then `250 um`

### Test 3: overlap validation

- capture a `3 x 3` tile grid
- verify neighboring tiles overlap by about the expected amount
- verify there is no obvious skipped or duplicated motion step

### Test 4: focus-window validation

- run a `2 mm x 2 mm` scan
- inspect center and corners for edge sharpness
- if corner sharpness fails, reduce the ROI size

## Dataset Collection Target

For each workflow:

- `10` pilot scans on different samples
- `3` sessions on different days
- `200 to 300` manually reviewed candidates

That is enough to start tuning thresholds and candidate ranking.

## Required Metadata Per Scan

- `sample_id`
- `material`
- `substrate`
- `oxide_thickness_nm`
- `objective`
- `exposure`
- `illumination recipe`
- `scan_width_mm`
- `scan_height_mm`
- `overlap_fraction`
- `operator`
- `date`

## Success Criteria

The protocol is good enough to scale when:

1. tile overlap is visually consistent across the full scan
2. focus is acceptable across the chosen ROI
3. optical appearance is stable enough that thresholds do not need retuning every scan
4. a reviewer can label surfaced candidates quickly without fighting obvious artifacts

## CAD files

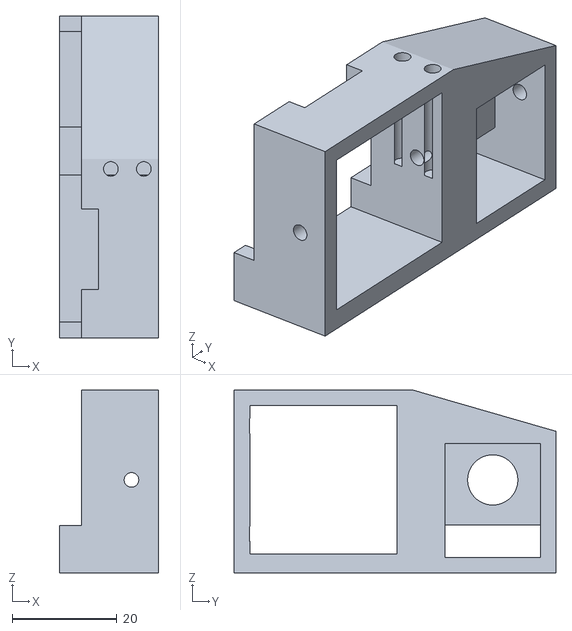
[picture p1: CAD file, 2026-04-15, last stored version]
donor_cad/uc2_micronstage/stl/Assembly_XY_stage_with_motors_v3_30_Mount_Nema_Motor_attachement_for_XYstage_v3.stl
19.0 x 61.6 x 35.0

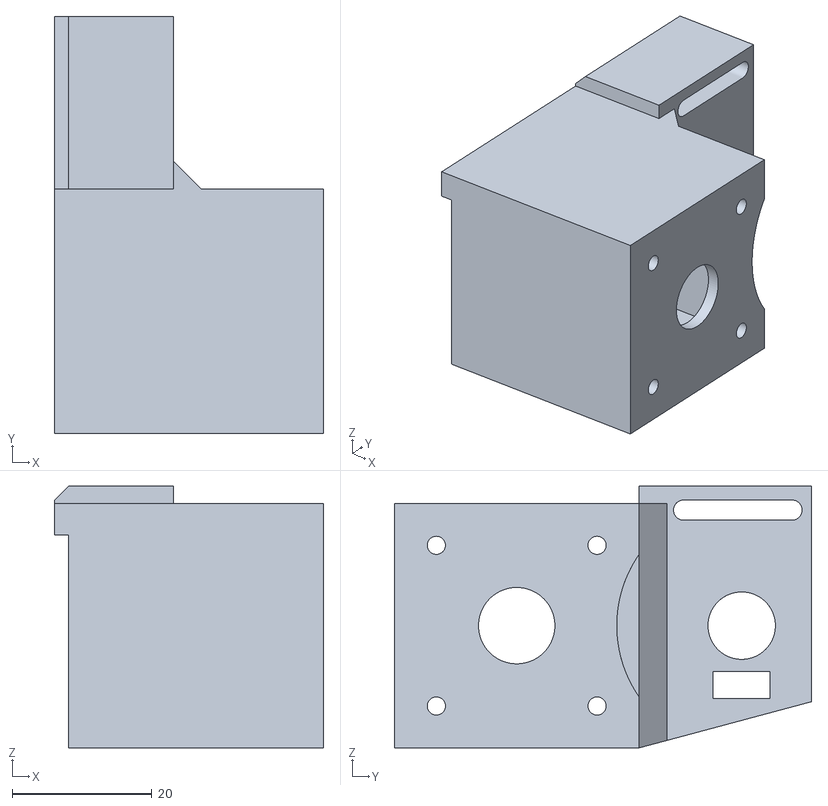
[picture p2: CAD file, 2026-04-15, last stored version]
zeiss_axio_xy_stage_freestanding/references/donor_stl/Assembly_XY_stage_with_motors_v3_cellSTORM_UC2_motorized_micrometer_motormount_1.stl
38.5 x 59.7 x 37.5

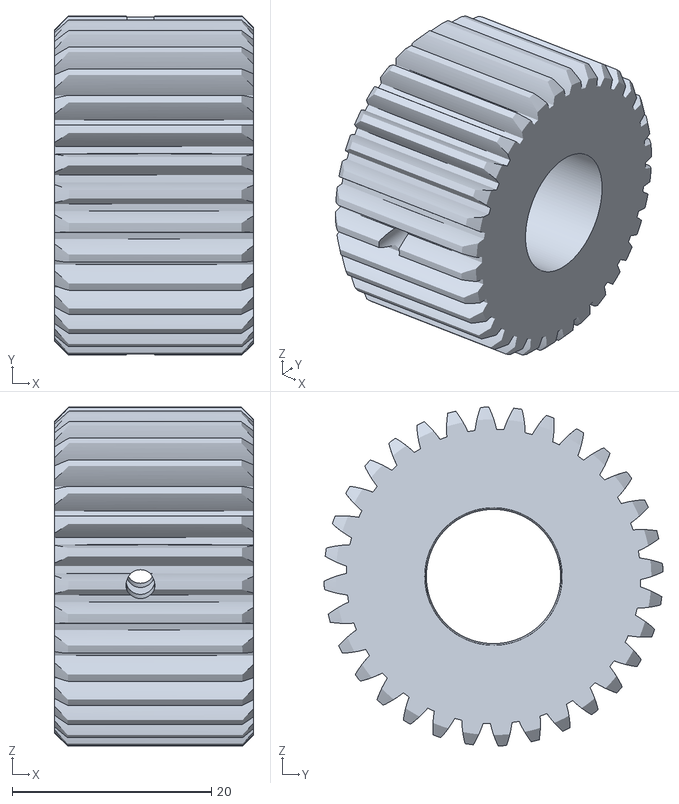
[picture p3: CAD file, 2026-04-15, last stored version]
donor_cad/uc2_micronstage/stl/Assembly_XY_stage_with_motors_v3_cellSTORM_UC2_motorized_micrometer_gear2_1.stl
20.0 x 34.0 x 34.0

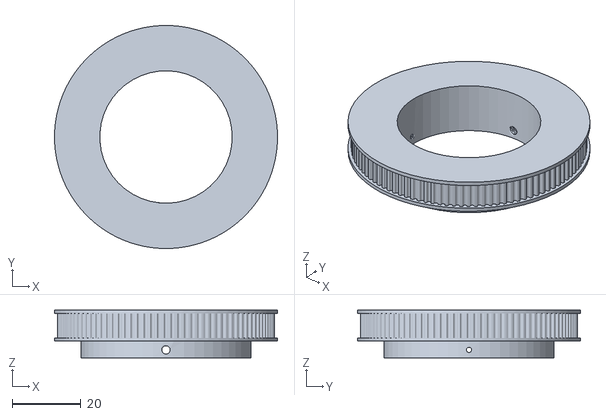
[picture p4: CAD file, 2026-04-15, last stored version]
zeiss_axio_xy_stage_freestanding/references/donor_stl/Assembly_XYTable_Aliepexress_00_XYTable_large_gear_29.stl
64.7 x 64.7 x 13.8

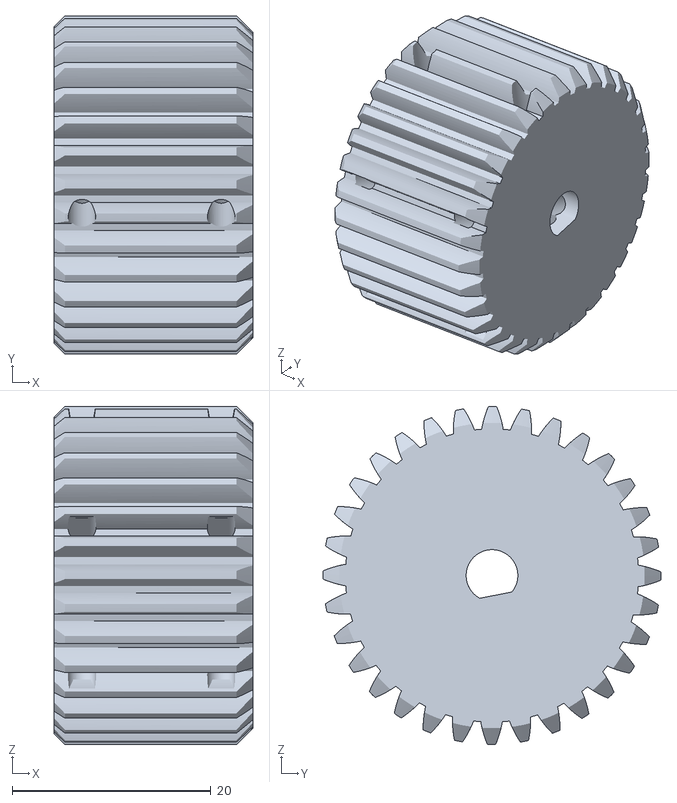
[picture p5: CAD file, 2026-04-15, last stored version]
donor_cad/uc2_micronstage/stl/Assembly_XY_stage_with_motors_v3_cellSTORM_UC2_motorized_micrometer_gear1_2.stl
20.0 x 34.0 x 34.0

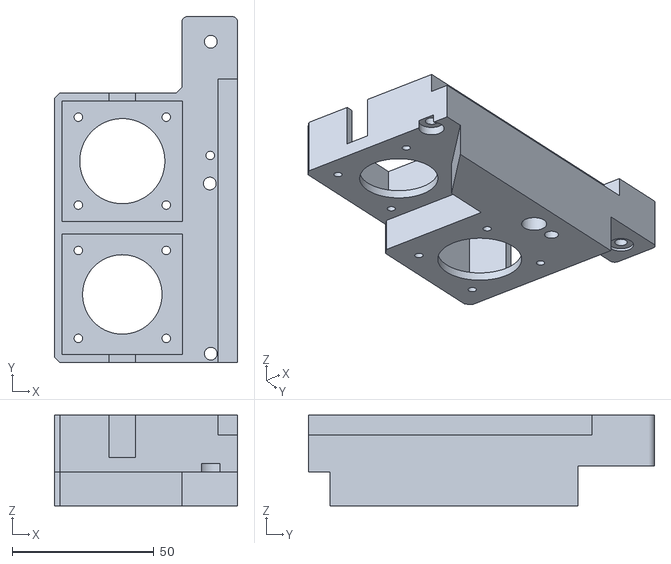
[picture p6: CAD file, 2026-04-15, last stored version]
zeiss_axio_xy_stage_freestanding/references/donor_stl/Assembly_XYTable_Aliepexress_30_XYTable_Aliexpress_motormount_4.stl
64.7 x 122.0 x 32.0

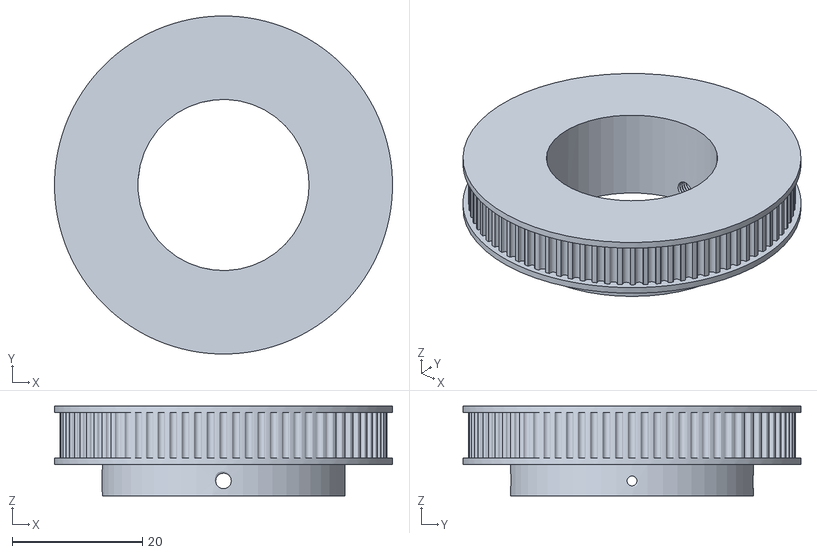
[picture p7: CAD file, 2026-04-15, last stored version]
zeiss_axio_xy_stage_freestanding/references/donor_stl/Assembly_XYTable_Aliepexress_00_XYTable_medium_gear_27.stl
51.9 x 51.9 x 13.8

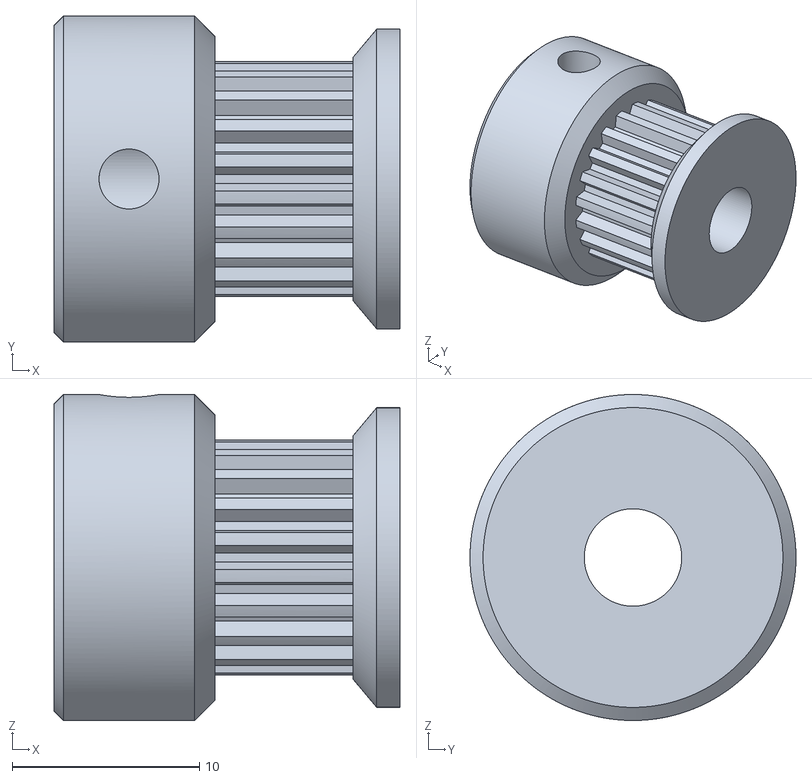
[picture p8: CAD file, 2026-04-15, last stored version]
donor_cad/uc2_motorized_xy_table/stl/Assembly_XYTable_Aliepexress_00_XYTable_pulley_30.stl
18.5 x 17.4 x 17.4

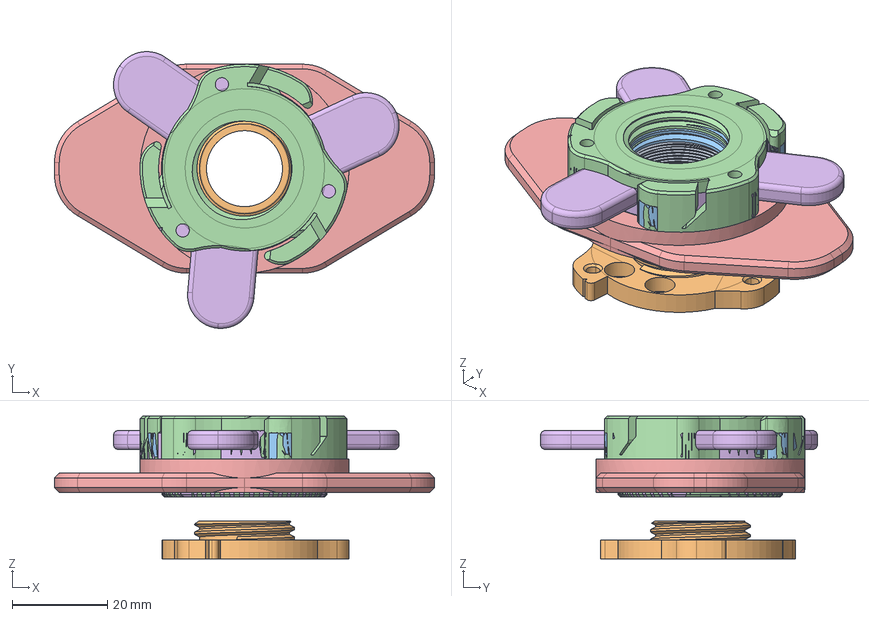
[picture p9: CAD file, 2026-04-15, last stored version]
donor_cad/puma/freecad/QuickRelease_v2.0.FCStd
80.0 x 58.3 x 30.0 mm
C-RMS_Thread
Base_thread
QR_Male_C_extn_1mm
QR_Male_C_extn_4mm
Trainer
Trainer_Male

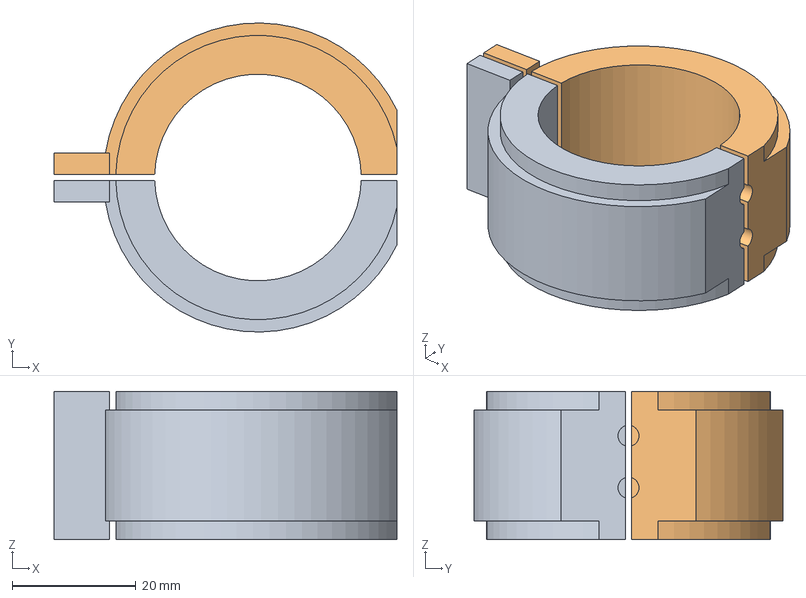
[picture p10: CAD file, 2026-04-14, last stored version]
zeiss_axio_cad/exports/step/preview_y_stage_pulley_left.step
55.5 x 50.0 x 24.0 mm

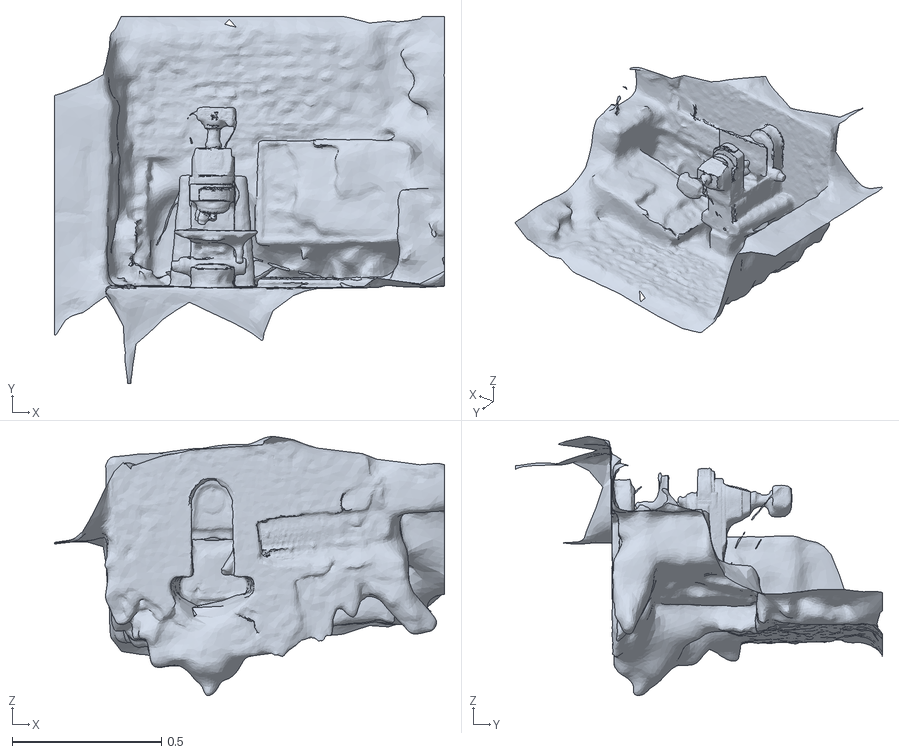
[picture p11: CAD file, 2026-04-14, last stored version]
zeiss_axio_cad/scan_input/Microscope_Scan.stl
1.31 x 1.23 x 0.87

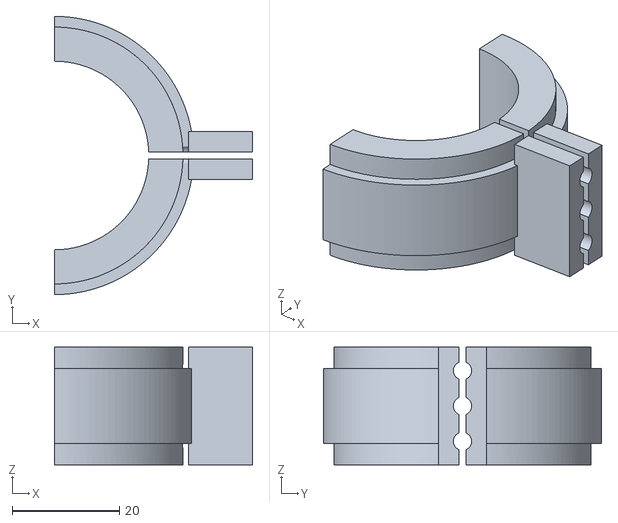
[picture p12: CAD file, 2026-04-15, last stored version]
zeiss_axio_xy_stage_freestanding/exports/stl/axio_y_knob_pulley_right_half.stl
37.0 x 52.0 x 22.0

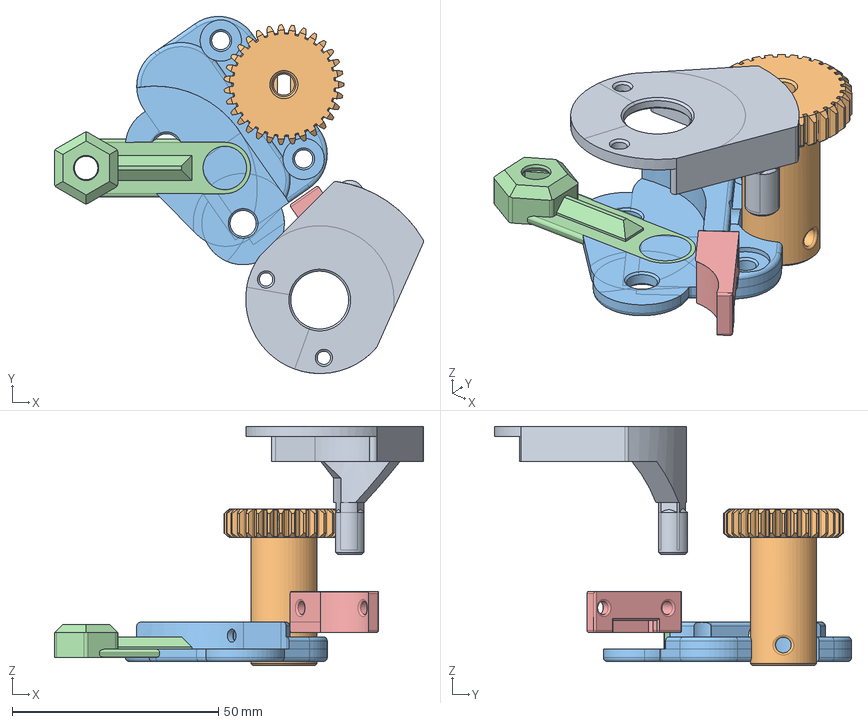
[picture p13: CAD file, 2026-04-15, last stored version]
donor_cad/puma/freecad/Z_Motor.FCStd
89.4 x 86.5 x 58.0 mm
Z_Probe
Motor_gear
Motor_attachment
Z_Yoke
Z_Limit_Sw_mount

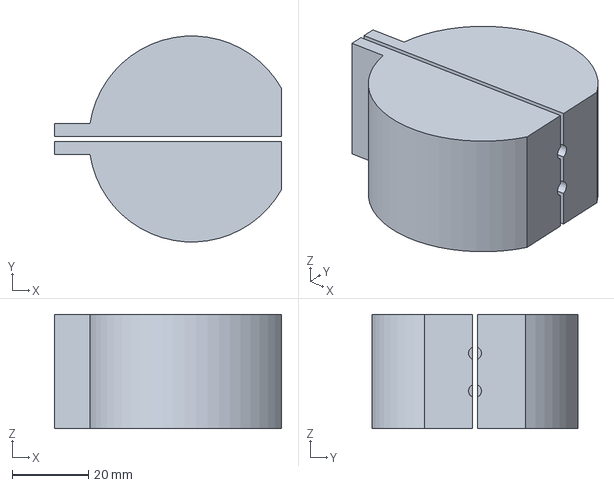
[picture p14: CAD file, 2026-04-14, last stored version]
zeiss_axio_cad/exports/step/focus_conical_clamp_pulley_left_half.step
59.5 x 54.0 x 30.0 mm

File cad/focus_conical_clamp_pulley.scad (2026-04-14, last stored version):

$fn = 128;

// Zeiss Axio left-focus conical clamp pulley
// First-pass parametric concept:
// - two mirrored clamp halves
// - tapered inner bore matching measured focus knob
// - smooth outer pulley body sized for GT2 belt contact

knob_d_end = 34.12;
knob_d_base = 37.52;
knob_height = 26.5;

clearance = 0.4;
wall = 5.0;
pulley_outer_d = 54.0;
pulley_height = 30.0;
split_gap = 1.2;

clamp_ear_width = 10.0;
clamp_ear_depth = 8.0;
clamp_ear_height = pulley_height;
clamp_hole_d = 3.4;
nut_capture_w = 6.2;
nut_capture_h = 2.7;

module tapered_bore() {
    cylinder(
        h = knob_height + 1.0,
        d1 = knob_d_base + clearance,
        d2 = knob_d_end + clearance
    );
}

module pulley_body() {
    difference() {
        cylinder(h = pulley_height, d = pulley_outer_d);
        translate([0, 0, 1.5]) tapered_bore();
    }
}

module clamp_ears() {
    for (side = [-1, 1]) {
        translate([
            side * ((pulley_outer_d / 2) + (clamp_ear_width / 2) - 1.0),
            0,
            0
        ])
        cube([clamp_ear_width, clamp_ear_depth, clamp_ear_height], center = true);
    }
}

module clamp_hardware() {
    for (zpos = [pulley_height * 0.33, pulley_height * 0.66]) {
        translate([0, 0, zpos - pulley_height / 2]) {
            rotate([90, 0, 0])
            cylinder(h = pulley_outer_d + 30, d = clamp_hole_d, center = true);

            translate([-(pulley_outer_d / 2 + clamp_ear_width / 2), 0, 0])
            rotate([90, 0, 0])
            linear_extrude(height = nut_capture_h, center = true)
            polygon(points = [
                [ nut_capture_w / 2, 0],
                [ nut_capture_w / 4,  nut_capture_w * 0.433],
                [-nut_capture_w / 4,  nut_capture_w * 0.433],
                [-nut_capture_w / 2, 0],
                [-nut_capture_w / 4, -nut_capture_w * 0.433],
                [ nut_capture_w / 4, -nut_capture_w * 0.433]
            ]);
        }
    }
}

module split_cut() {
    translate([0, 0, 0])
    cube([pulley_outer_d + 40, split_gap, pulley_height + 2], center = true);
}

module half_part(side = 1) {
    intersection() {
        difference() {
            union() {
                translate([0, 0, pulley_height / 2]) pulley_body();
                translate([0, 0, pulley_height / 2]) clamp_ears();
            }
            translate([0, 0, pulley_height / 2]) split_cut();
            translate([0, 0, pulley_height / 2]) clamp_hardware();
        }
        translate([side * 100, 0, pulley_height / 2])
        cube([200, 200, pulley_height + 10], center = true);
    }
}

translate([-40, 0, 0]) half_part(-1);
translate([ 40, 0, 0]) mirror([1, 0, 0]) half_part(-1);

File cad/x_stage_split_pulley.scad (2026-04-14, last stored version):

$fn = 128;

// Zeiss Axio X-stage split pulley
// Knob diameter measured: 27.8 mm

knob_d = 27.8;
clearance = 0.5;
pulley_outer_d = 44.0;
pulley_height = 18.0;
hub_height = 24.0;
split_gap = 1.0;

ear_width = 9.0;
ear_depth = 8.0;
hole_d = 3.4;
nut_capture_w = 6.2;
nut_capture_h = 2.7;

module body() {
    difference() {
        union() {
            cylinder(h = hub_height, d = pulley_outer_d - 4.0);
            translate([0, 0, (hub_height - pulley_height) / 2])
            cylinder(h = pulley_height, d = pulley_outer_d);
        }
        translate([0, 0, -1])
        cylinder(h = hub_height + 2, d = knob_d + clearance);
    }
}

module ears() {
    for (side = [-1, 1]) {
        translate([
            side * ((pulley_outer_d / 2) + (ear_width / 2) - 1.0),
            0,
            hub_height / 2
        ])
        cube([ear_width, ear_depth, hub_height], center = true);
    }
}

module hardware() {
    for (zpos = [hub_height * 0.35, hub_height * 0.7]) {
        translate([0, 0, zpos]) {
            rotate([90, 0, 0])
            cylinder(h = pulley_outer_d + 30, d = hole_d, center = true);

            translate([-(pulley_outer_d / 2 + ear_width / 2), 0, 0])
            rotate([90, 0, 0])
            linear_extrude(height = nut_capture_h, center = true)
            polygon(points = [
                [ nut_capture_w / 2, 0],
                [ nut_capture_w / 4,  nut_capture_w * 0.433],
                [-nut_capture_w / 4,  nut_capture_w * 0.433],
                [-nut_capture_w / 2, 0],
                [-nut_capture_w / 4, -nut_capture_w * 0.433],
                [ nut_capture_w / 4, -nut_capture_w * 0.433]
            ]);
        }
    }
}

module split_cut() {
    translate([0, 0, hub_height / 2])
    cube([pulley_outer_d + 40, split_gap, hub_height + 2], center = true);
}

module half_part(side = 1) {
    intersection() {
        difference() {
            union() {
                body();
                ears();
            }
            split_cut();
            hardware();
        }
        translate([side * 100, 0, hub_height / 2])
        cube([200, 200, hub_height + 10], center = true);
    }
}

translate([-35, 0, 0]) half_part(-1);
translate([ 35, 0, 0]) mirror([1, 0, 0]) half_part(-1);

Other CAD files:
zeiss_axio_xy_stage_freestanding/references/donor_stl/Assembly_XYTable_Aliepexress_00_XYTable_pulley_28.stl
zeiss_axio_xy_stage_freestanding/exports/stl/axio_x_knob_pulley_left_half.stl
donor_cad/puma/freecad/CNC_Stage_1.FCStd
cad/y_stage_split_pulley.scad
donor_cad/puma/freecad/CNC_Stage_2.FCStd
donor_cad/puma/freecad/Focus_Gears.FCStd
donor_cad/puma/freecad/Stage.FCStd
donor_cad/puma/freecad/XY_Stabiliser.FCStd
donor_cad/uc2_micronstage/inventor/30_Mount_Nema_Motor_attachement_for_XYstage_v3.ipt
donor_cad/uc2_micronstage/inventor/cellSTORM_UC2_motorized_micrometer_gear1.ipt
donor_cad/uc2_micronstage/inventor/cellSTORM_UC2_motorized_micrometer_gear2.ipt
donor_cad/uc2_micronstage/inventor/cellSTORM_UC2_motorized_micrometer_motormount.ipt
donor_cad/uc2_motorized_xy_table/inventor/00_XYTable_large_gear.ipt
donor_cad/uc2_motorized_xy_table/inventor/00_XYTable_medium_gear.ipt
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

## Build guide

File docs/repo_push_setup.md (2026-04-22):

# Windows Repo Push Setup

## What We Need

To let me push this workspace to `https://github.com/xulab2d/FlakeID`, this machine needs:

1. Git for Windows installed
2. GitHub authentication available to Git

Right now, `git` is not installed or not on `PATH`, so I cannot push yet.

## Easiest Setup Path

The simplest route is usually:

1. install **Git for Windows**
2. sign in through the Git credential prompt the first time we push

If you prefer a GUI-first workflow, **GitHub Desktop** also works, but plain Git is enough for me to handle the rest.

## After Git Is Installed

I can then:

1. initialize this folder as a git repo if needed
2. connect it to `xulab2d/FlakeID`
3. replace the old repo contents with this new scaffold
4. commit on a clean branch
5. push it to GitHub

## If You Want Me To Do The Push

Once Git is installed, I will still need:

- your GitHub username already has push access to `xulab2d/FlakeID`
- a browser-based sign-in prompt or stored credential to complete authentication

## Safe Rollout Suggestion

Even though you said the old contents can be replaced, I recommend:

1. push this as a new branch first
2. inspect GitHub once
3. merge it into `main` only after you are happy

That keeps the repo recoverable if there is anything worth preserving in the old project.

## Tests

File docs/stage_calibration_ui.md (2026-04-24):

# Stage Calibration UI

## Goal

Provide a safe manual-control window for:

- stage boundary mapping
- belt-friendly motion tuning
- scan ROI setup
- launching a raster capture run

## Launch

From the repo root:

```powershell
powershell.exe -NoProfile -ExecutionPolicy Bypass -File scripts\launch_stage_ui.ps1 `
  -Config configs/lab.example.toml
```

## What The UI Does

- reads live GRBL status
- jogs `X` and `Y` by a chosen step size
- lets you lower jog feed before testing
- reads and writes GRBL max-rate settings `$110/$111`
- reads and writes GRBL acceleration settings `$120/$121`
- lets you mark current position as safe min/max bounds
- saves those bounds and motion values back into the config file
- lets you mark `left`, `right`, `top`, and `bottom` scan edges for the next scan ROI
- estimates raster size from FOV and overlap
- launches `run-scan` in a separate PowerShell window
- keeps scan photos organized under `photos/scans/...`

## Recommended Starting Values

If belts are skipping, start here:

- jog feed: `20 to 40 mm/min`
- x max rate: `40 to 80 mm/min`
- y max rate: `40 to 80 mm/min`
- x accel: `1 to 3 mm/s^2`
- y accel: `1 to 3 mm/s^2`

Then increase only after motion becomes repeatable.

## Safe Workflow

1. Open the UI.
2. Click `Refresh Status`.
3. Lower feed/rate/acceleration before any bigger move.
4. Use small jog steps first.
5. Mark safe min/max bounds only at backed-off safe locations, not at hard stops.
6. Mark the scan ROI edges for the flake region you want to raster.
7. Fill in sample metadata and click `Start Scan`.

## Notes

- Manual knob motion still does not update GRBL coordinates automatically.
- If you move the stage by hand, re-zero or re-establish your session coordinate reference before trusting the display.
- `Feed Hold`, `Resume`, and `Soft Reset` are exposed in the UI for bring-up convenience, but use them carefully.
- Jog motion is sent as feed-controlled `G1`, not `G0` rapids, so the jog-feed field should now have a real effect.
- On this current GRBL/UNO path, writing controller settings works more reliably than reading them back. Treat the UI fields as the intended values and verify by actual stage behavior.
- For the current default watched-folder camera flow, set EOS Utility once to save into `photos/incoming`. Each scan then copies images into its own per-scan folder automatically.

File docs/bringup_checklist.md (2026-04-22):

# Bring-Up Checklist

## Hardware Bring-Up

1. Confirm which serial port is the GRBL controller.
2. Manually verify that `$X`, `?`, and a tiny `G0` move behave correctly before any scan automation.
3. Measure the real XY travel per commanded unit and confirm whether your GRBL coordinates already correspond to micrometers or need a conversion.
4. Pick one objective for the first automated pipeline and keep it fixed during early dataset collection.
5. Install `pyserial` before attempting live automated scans from Python, so the GRBL serial connection can stay open.

## Camera Bring-Up

1. Turn on the Canon camera and confirm a repeatable tethered capture path on Windows.
2. Replace `camera.capture_command` in [configs/lab.example.toml](../configs/lab.example.toml) with the real capture command.
3. Lock exposure, white balance, ISO, and illumination settings.
4. Save all raw images with stable filenames and timestamps.

## Optical Calibration

1. For graphene on 285 nm and hBN on 90 nm, collect 30 to 50 blank-substrate fields each.
2. Repeat blank-field capture at the start and end of at least three sessions.
3. Verify whether brightness drift is dominated by lamp intensity, white balance, or vignetting.
4. Build one flat-field file per objective and illumination setting.

## Scan Geometry

1. Measure the true field of view in micrometers for the chosen objective.
2. Update `scan.fov_width_um` and `scan.fov_height_um` accordingly.
3. Start with overlap near 10 to 15%.
4. Run `scan-plan` on a small region first and confirm tile spacing on the microscope.

## Dataset Bootstrapping

1. Run 10 small scans per workflow before attempting a full slide.
2. Review every surfaced candidate and label it `accept`, `reject`, or `ambiguous`.
3. Save a short note for hard negatives such as tape residue, dust, fringes, or focus failure.
4. Keep Raman or AFM confirmations for a smaller gold-standard subset.

## First Success Criteria

1. The system should not miss obviously usable flakes in a test region.
2. The false-positive rate should be low enough that a human can review a scan in minutes, not hours.
3. The same thresholds should work across multiple days without retuning.
4. The catalog should be rich enough to export a first supervised dataset.

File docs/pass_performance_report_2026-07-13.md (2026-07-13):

# FlakeID Pass Performance Report

Generated 2026-07-13 from saved local FlakeID artifacts in `outputs/` and `photos/scans/`.

This report covers the deterministic proposal pass, the first ML triage pass, the second good-flake pass, and the autofocus work. The main caveat is that the deterministic pass is a proposal generator, not a closed-set classifier. Its "performance" is best read from proposal yield and full-scan funnel counts unless we add exhaustive ground truth over all pixels or all possible flakes.

## Executive Summary

- Graphene first-pass logistic classification is strong on the reviewed validation set: 96.6% accuracy, 95.3% precision, 95.3% recall, and 95.3% F1 for flake-present labels.
- Graphene usable-thickness classification is also useful but less perfect: 87.8% accuracy and 90.4% F1. This is the pass that turns "flake" into likely few-layer/usable material before ranking.
- Graphene second-pass good/bad ranking has high ranking quality, with AP 0.703, ROC AUC 0.940, and P@10 0.900. Its thresholded precision is lower, 60.4%, because it is deliberately recovering many good candidates from a small positive class.
- hBN first-pass torch classification is the strongest hBN model so far: 99.4% validation accuracy, 100.0% precision, 92.0% recall, and 95.8% F1 at threshold 0.90.
- hBN second-pass good/bad is the hardest piece. The best review-sorting version is the region-domain model: 91.9% accuracy, 90.0% precision, 47.4% recall, 62.1% F1, AP 0.610, and P@10 0.900. That is a high-precision sorter, not yet a high-recall final classifier.
- Autofocus work found that ROI selection mattered more than the specific sharpness metric. A larger corner ROI around 0.50 preserved chip-corner context and reduced failures where the fine pass chased a worse frame.

## Pass Definitions

1. **Deterministic proposal pass**
   - Purpose: find anything flake-like or feature-like at high recall before any classifier decides whether it is worth review.
   - Main implementations: `src/flake_ml/detection/graphene.py`, `src/flake_ml/detection/opencv_contours.py`, and `src/flake_ml/detection/qumus_lab.py`.
   - Output: candidate bounding boxes, physical-size estimates, detector scores, and color/shape features.

2. **First ML pass**
   - Purpose: decide whether a detector proposal is actually a flake, and for graphene also whether it has usable thickness.
   - Graphene implementation: hand-feature logistic models in `src/flake_ml/learning/candidate_baseline.py`.
   - hBN implementation: torch image-plus-metadata model trained by `scripts/train_first_pass_torch.py`.

3. **Second pass / good-flake ranking**
   - Purpose: rank first-pass flakes by whether they are actually worth pursuing.
   - Implementation: torch good/bad classifier in `src/flake_ml/learning/candidate_good_bad_torch.py`.
   - Output: `good_probability`, `predicted_good`, ranked galleries, and final candidate JSON.

## Validation Metrics

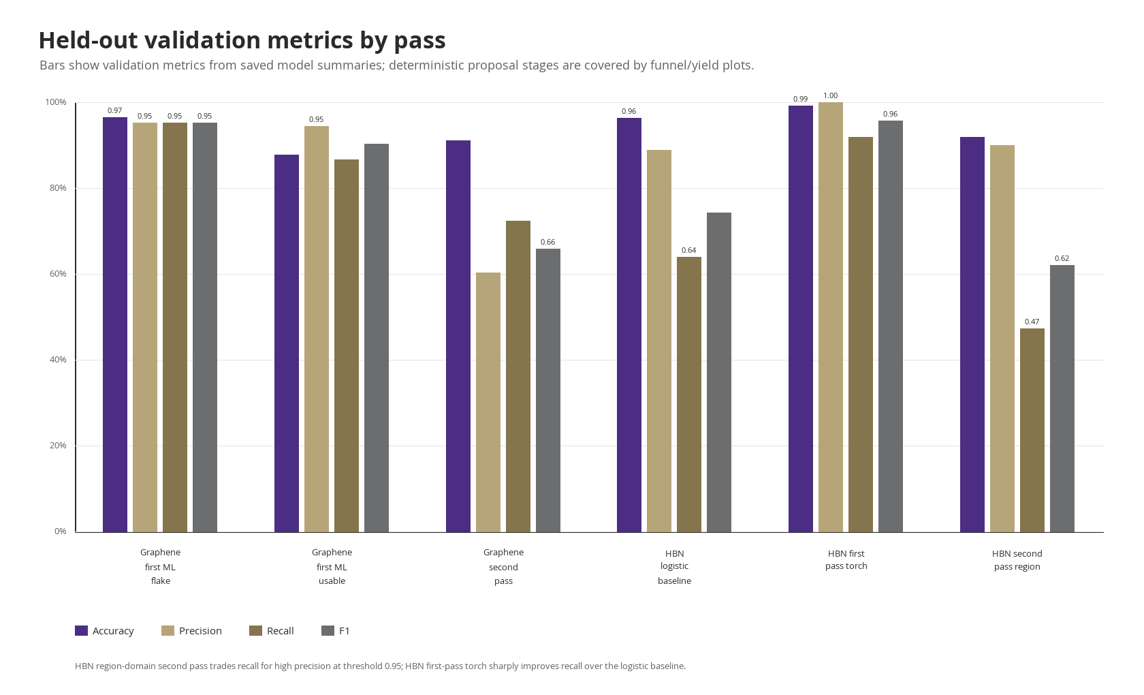
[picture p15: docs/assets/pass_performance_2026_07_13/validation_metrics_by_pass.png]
Held-out validation metrics by pass


| Material | Pass / model | Eval set | Threshold | Accuracy | Precision | Recall | F1 | Ranking metrics |
| --- | --- | ---: | ---: | ---: | ---: | ---: | ---: | --- |
| Graphene | First ML flake-present logistic | 232 val | 0.50 | 96.6% | 95.3% | 95.3% | 95.3% | -- |
| Graphene | First ML usable-thickness logistic | 90 val | 0.50 | 87.8% | 94.5% | 86.7% | 90.4% | -- |
| Graphene | Second-pass good/bad torch, run 3 | 342 val | 0.95 | 91.2% | 60.4% | 72.5% | 65.9% | AP 0.703, AUC 0.940, P@10 0.900 |
| hBN | First-pass logistic baseline | 312 val | 0.50 | 96.5% | 88.9% | 64.0% | 74.4% | -- |
| hBN | First-pass torch | 312 val | 0.90 | 99.4% | 100.0% | 92.0% | 95.8% | AP 0.955, AUC 0.980 |
| hBN | Early second-pass good/bad torch | 42 val | 0.65 | 69.0% | 50.0% | 84.6% | 62.9% | AP 0.578, AUC 0.732, P@10 0.400 |
| hBN | Combined second-pass good/bad torch | 136 val | 0.90 | 83.1% | 42.3% | 57.9% | 48.9% | AP 0.433, AUC 0.771, P@10 0.400 |
| hBN | Region-domain second-pass good/bad torch | 136 val | 0.95 | 91.9% | 90.0% | 47.4% | 62.1% | AP 0.610, AUC 0.763, P@10 0.900 |
| hBN | Region-gate v2 variant | 136 val | 0.05 | 86.0% | 0.0% | 0.0% | 0.0% | AP 0.232, AUC 0.399, P@10 0.300 |

The hBN region-gate v2 row is included as a warning. It gets superficially high accuracy by predicting no positives on an imbalanced validation set. Precision, recall, and F1 correctly show that this is not a usable classifier.

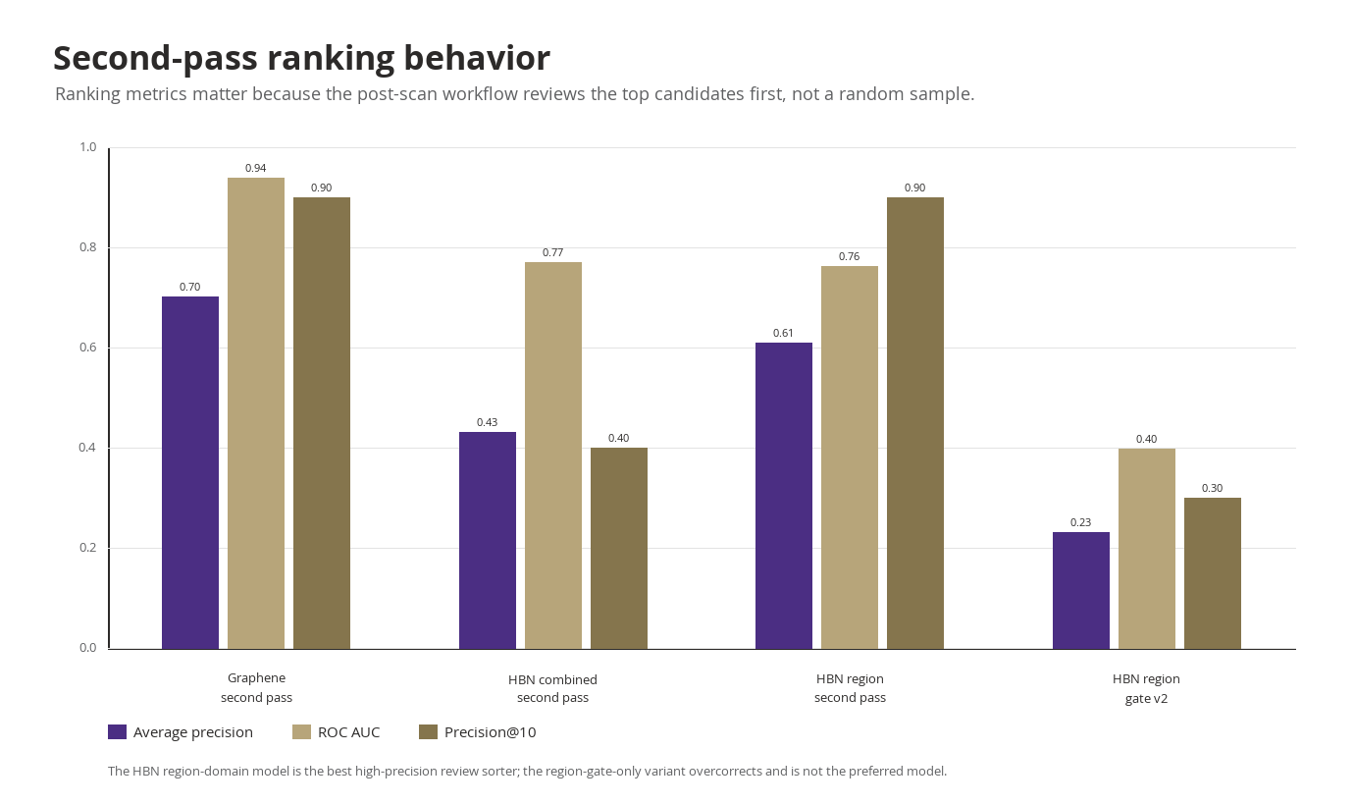
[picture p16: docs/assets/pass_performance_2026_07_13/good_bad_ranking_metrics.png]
Second-pass ranking metrics


The ranking plot is especially relevant for post-scan review. Even when thresholded F1 is modest, a high P@10 means the top of the ranked list is productive for a human or an automated follow-up workflow. That is why the hBN region-domain model is more useful than the combined model despite similar ROC AUC.

## Deterministic Proposal Yield And Full-Scan Funnels

| Material / run | Images | Detector or reviewed proposals | First-pass selected | Second-pass good | Notes |
| --- | ---: | ---: | ---: | ---: | --- |
| Graphene reviewed labels | -- | 1,244 binary reviews | 495 flakes in labels | -- | Reviewed proposal yield: 39.8% flake |
| hBN reviewed labels | -- | 1,531 binary reviews | 160 flakes in labels | -- | Reviewed proposal yield: 10.5% flake |
| Graphene scan `20260514T014605Z_flake_grid_001` | 316 | 7,023 detector candidates | 30 usable first-pass candidates | 3 good | Graphene detector plus logistic first pass, then good/bad torch |
| hBN scan `20260515T051601Z_Isaac_BN1r2` | 2,112 | 8,350 size-pass candidates | 660 first-pass flakes | 67 good | hBN material mode, first-pass torch threshold 0.90 |
| hBN scan `20260520T044855Z_IsaacV_AutoBN01` | 1,093 | 7,858 size-pass candidates | 0 at threshold 0.50 | 0 good | Fallback ranked top 1,500 near-zero first-pass scores; domain/threshold stress case |

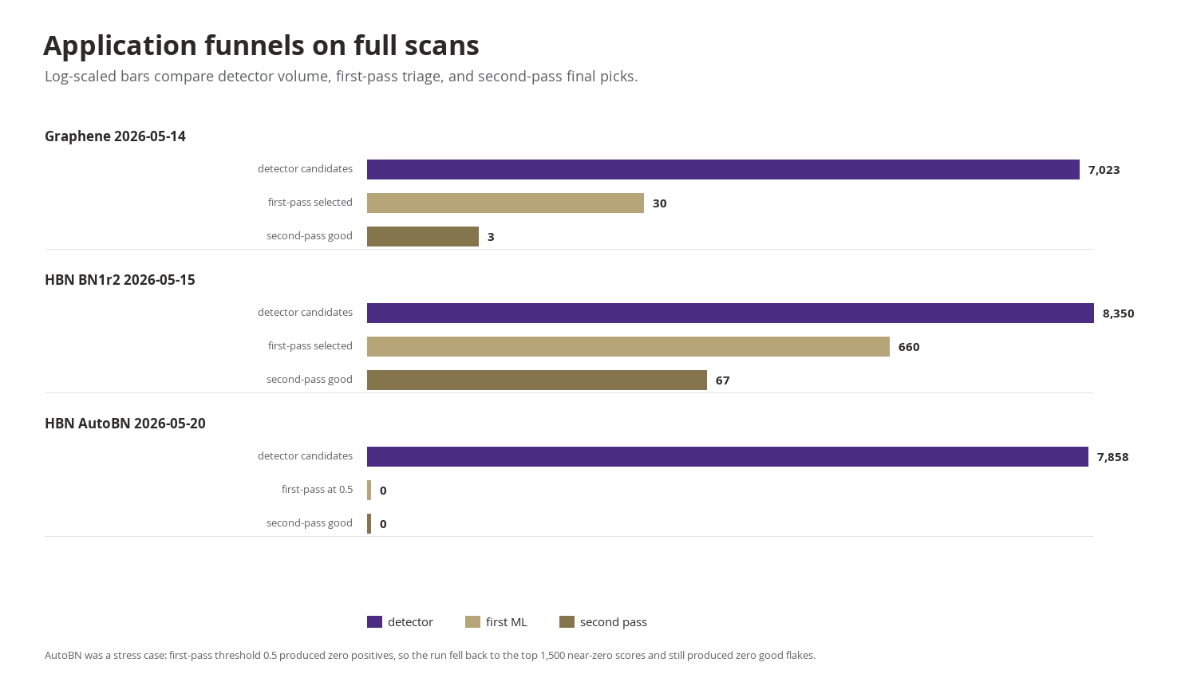
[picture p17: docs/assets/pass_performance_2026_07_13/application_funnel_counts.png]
Application funnel counts


The full-scan funnels show the operational compression. Graphene went from 7,023 detector candidates to 30 first-pass candidates to 3 final good candidates. The successful hBN BN1r2 scan went from 8,350 detector candidates to 660 first-pass flakes to 67 good candidates. The later AutoBN run shows a generalization failure: the first-pass model produced zero positives at the requested threshold and the fallback still produced zero good candidates.

One bookkeeping caveat: the BN1r2 post-scan summary is marked `material: hbn`, but its cached detector JSON is named `graphene_detector_scan.json`. The report treats it as hBN because the downstream post-scan material mode, first-pass model, and second-pass model are hBN-specific.

## Visual Category Grids

These grids show what the three pass categories look like in practice. The first column is a deterministic feature that did not pass first ML. The second is a first-pass ML flake that was not one of the final good picks. The third is a second-pass good candidate.

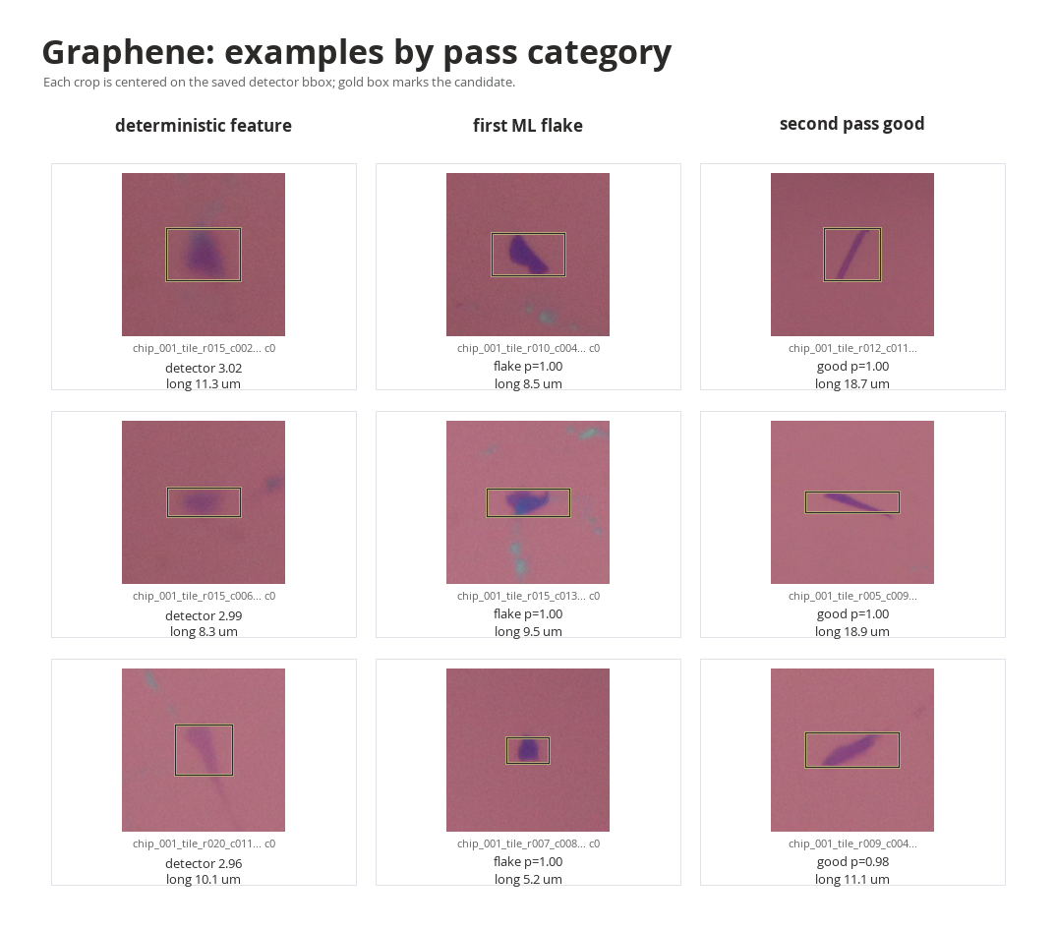
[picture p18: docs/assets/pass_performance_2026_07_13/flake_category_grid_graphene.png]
Graphene category grid


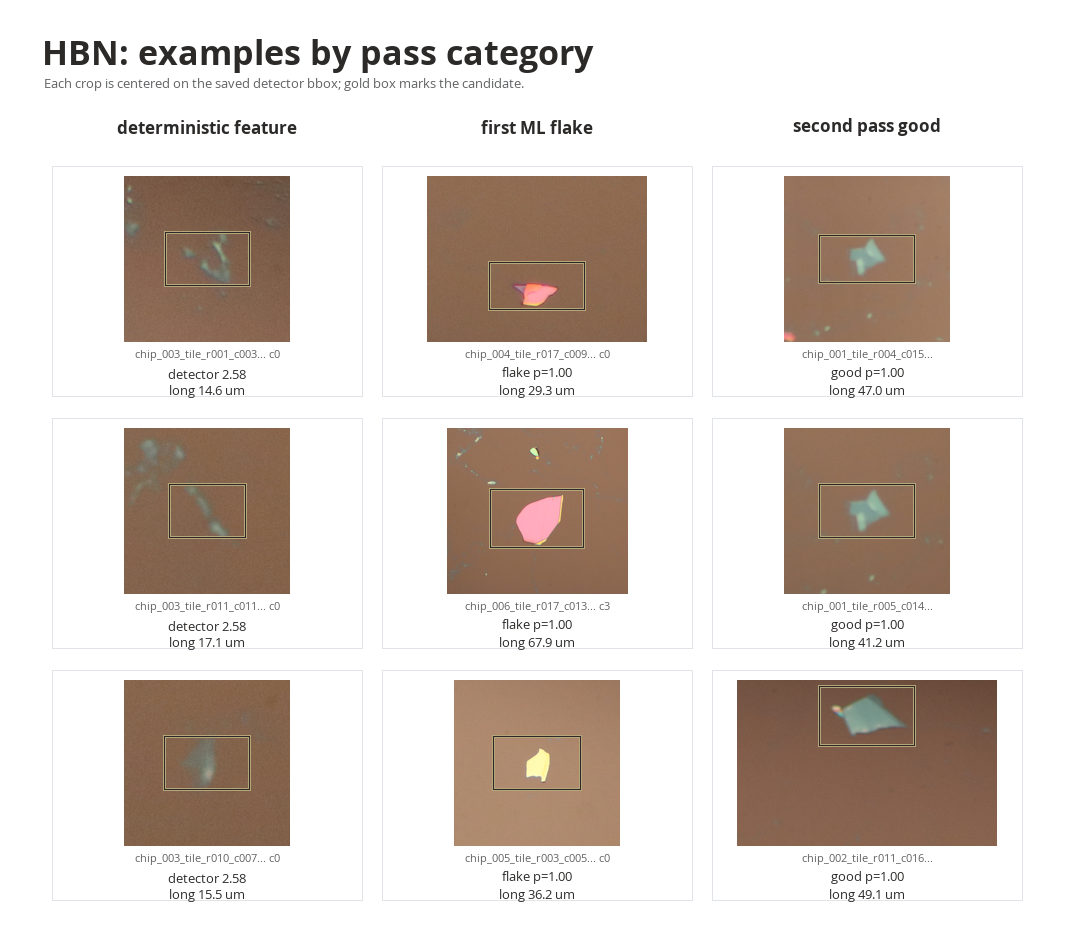
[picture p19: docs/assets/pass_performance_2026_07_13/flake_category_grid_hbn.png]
hBN category grid


The grids also explain the qualitative difference between graphene and hBN. Graphene candidates often appear as subtle purple/dark contrast changes on the 285 nm oxide background. hBN candidates include much more color diversity and more nuisance objects, including bright/pink regions that motivated the region-domain and pink-veto work.

## Deterministic Methodology

The deterministic layer is deliberately conservative. It tries to propose candidate regions, not decide final utility.

- `Graphene285nmDetector` white-balances from image borders, estimates local background, and scores color/luminance anomalies using signals such as red-green, blue-green, purple shift, chroma delta, darkness, local contrast, edge support, compactness, fill ratio, and size. It then runs morphology and connected-component filtering to emit scored boxes.
- `OpenCvContourFlakeDetector` uses LAB/color preprocessing, contour extraction, Canny/edge information, foreground masks, and material-specific plausibility filters. For hBN it adds color-region constraints, substrate/ring checks, shape filters, and size filters to suppress scratches, dirt, and line-like contours.
- `QumusLabDetector` is a LAB-equalized detector with material-specific plausible masks, foreground thresholds, optional benchmark profiles, and edge/shape filters. It is designed to be more substrate-aware and configurable for hBN and graphene.
- In Qumus LAB deterministic post-scan mode, `src/flake_ml/post_scan.py` can write all size-pass detector candidates as deterministic flake predictions with probability 1.0. That is a workflow fallback, not a learned probability estimate.

Because the detector proposes boxes without exhaustive negative sampling, accuracy/precision/recall are not well-defined for the deterministic pass alone. The meaningful detector-level numbers currently available are candidate volume, reviewed-label yield, and downstream survival through the first and second passes.

## ML Methodology

### Graphene first pass

The graphene first-pass models are logistic classifiers trained from reviewed detector candidates. The feature vector includes detector score, candidate area, bounding-box dimensions, tile-level candidate counts, RGB/HSV summary statistics, luma variation, fill ratio, compactness, purple shift, darkness, chroma delta, color anomaly, contrast, edge score, and aspect ratio.

Two graphene logistic tasks are trained from the same review set:

- `flake_present`: flake vs no-flake. Validation: 81 TP, 143 TN, 4 FP, 4 FN.
- `usable_thickness`: few-layer/usable vs thick among flakes. Validation: 52 TP, 27 TN, 3 FP, 8 FN.

The first production graphene funnel applies both thresholds at 0.50, so a candidate must look like a flake and look thickness-usable before it is passed to the good/bad ranker.

### hBN first pass

The hBN first-pass torch model uses a pretrained MobileNetV3-Small image backbone plus metadata features. Candidate crops are generated with surrounding context and a 0.55 padding fraction, then trained against `hbn_first_pass_candidate_reviews.json`. Training used an 80/20 split, seed 13, weighted sampling, class-weighted BCE, image size 224 px, and 80 epochs.

The recommended threshold from validation is 0.90. At that threshold the validation split had 23 TP, 287 TN, 0 FP, and 2 FN. This is a major improvement over the hBN logistic baseline, mostly by lifting recall from 64.0% to 92.0% while removing false positives on the validation split.

### Second-pass good/bad models

The good/bad models use the same broad architecture family: MobileNetV3-Small crop features plus metadata. Metadata includes detector score, physical size, RGB/HSV summaries, channel differences, shape features, edge/contrast features, and, for hBN region experiments, color-region descriptors.

Graphene second-pass training used 1,839 labeled candidates, with 178 positives and 1,661 negatives. The chosen run used image size 192 px, 14 epochs, learning rate 0.00025, and threshold 0.95.

hBN second-pass training evolved through several attempts:

- Early hBN model: only 196 labels. It had good recall, 84.6%, but weak precision, 50.0%.
- Combined hBN model: 856 labels. It was more stable but still low precision, 42.3%.
- Region-domain hBN model: same 856 labels plus color-region gating/metadata and pink-veto logic. It reached 90.0% precision and P@10 of 0.900, at the cost of recall.
- Region-gate v2: an overcorrection. It predicted no positives on validation, so it should be treated as a failed variant rather than an operational model.

## Autofocus Summary

The autofocus effort focused on failure cases where the runtime began at a good coarse frame, then moved to a worse fine-frame choice. The benchmark compared the current chip-corner boundary/focus score with Tenengrad, variance of Laplacian, modified Laplacian, and Brenner-style metrics over corner crops and edge strips.

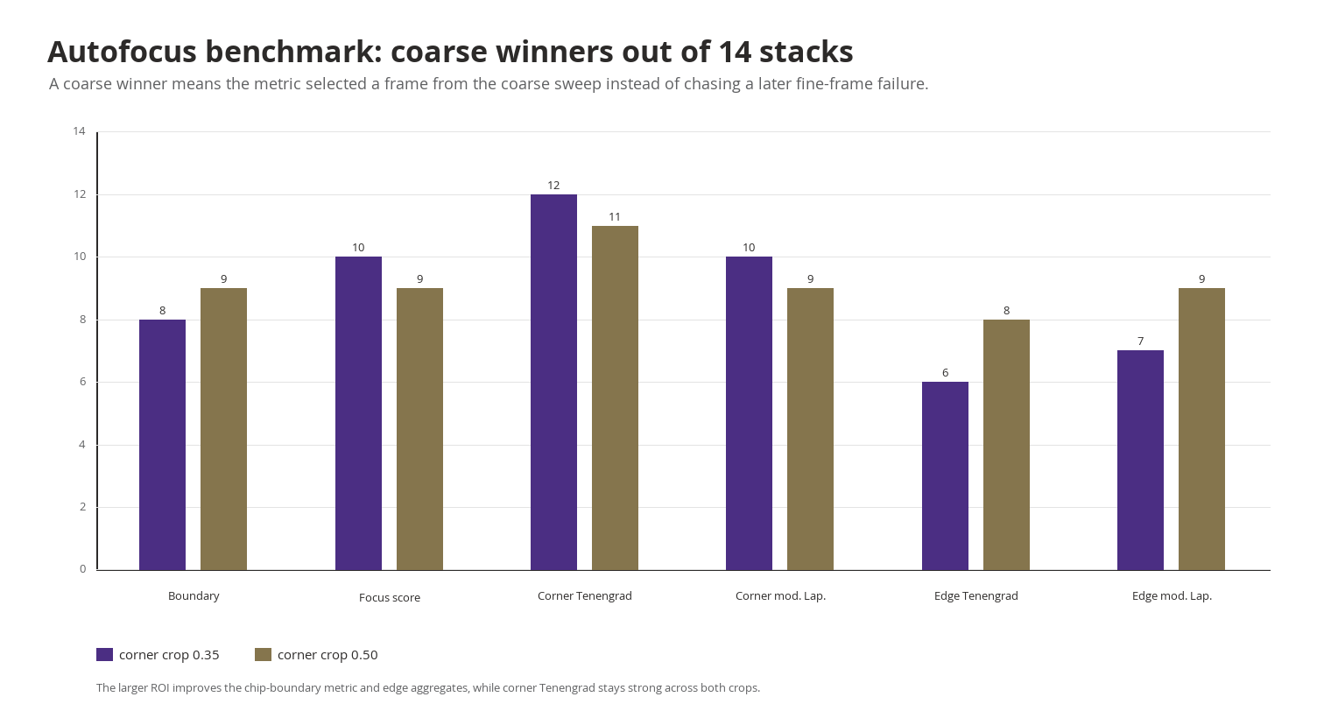
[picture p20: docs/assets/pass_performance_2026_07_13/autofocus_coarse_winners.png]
Autofocus coarse winners


Across 14 saved autofocus stacks, larger corner crops improved or stabilized the metrics that rely on chip-edge context:

- Boundary metric: 8/14 coarse winners at crop 0.35, 9/14 at crop 0.50.
- Edge harmonic-mean Tenengrad: 6/14 coarse winners at crop 0.35, 8/14 at crop 0.50.
- Edge harmonic-mean modified Laplacian: 7/14 coarse winners at crop 0.35, 9/14 at crop 0.50.
- Corner Tenengrad was strong in both settings: 12/14 at crop 0.35 and 11/14 at crop 0.50.

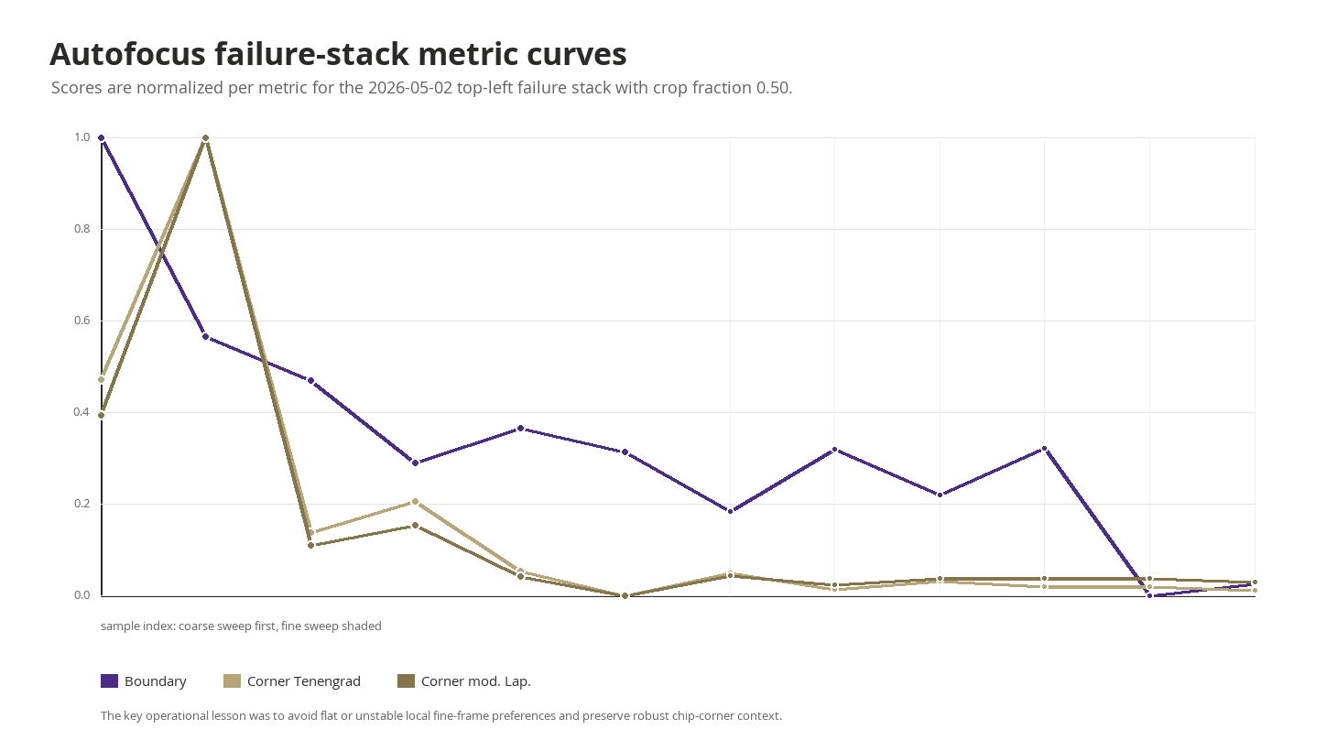
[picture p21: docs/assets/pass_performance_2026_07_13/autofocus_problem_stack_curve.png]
Autofocus failure-stack curves


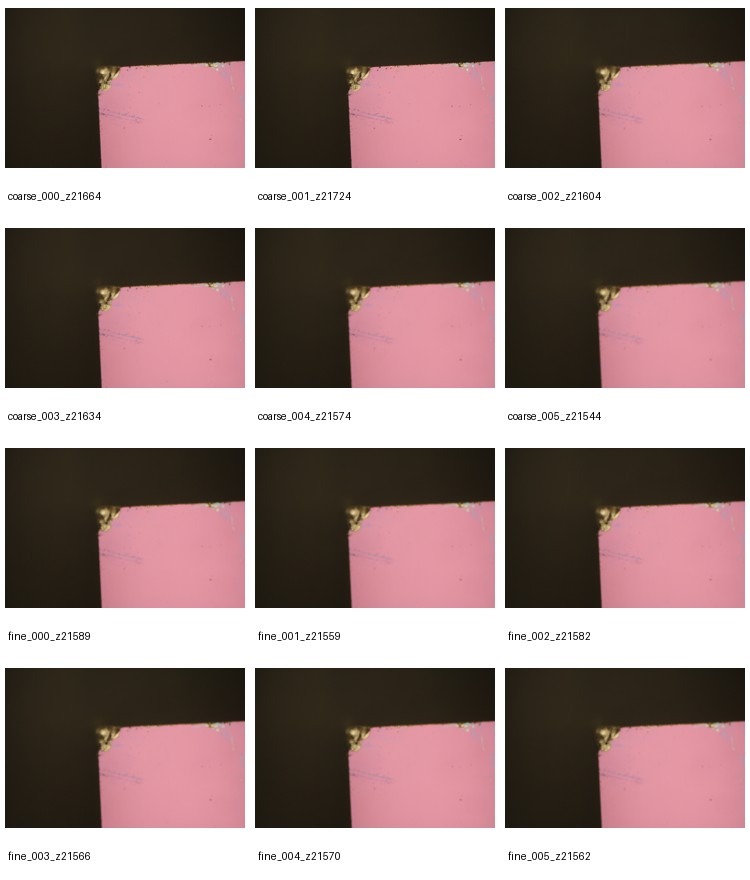
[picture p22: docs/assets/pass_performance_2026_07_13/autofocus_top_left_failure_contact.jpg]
Autofocus top-left failure contact sheet


The practical recommendation is to use a larger corner ROI around 0.50, keep the chip-corner boundary metric as the global objective, use a derivative metric as a local tie-breaker, and avoid taking fine-pass moves when the curve is flat or unstable.

## Most Useful Next Plots

- Precision-recall curves and threshold sweeps per material, especially for hBN second-pass variants.
- Calibration plots for first-pass and second-pass probabilities. The AutoBN run suggests hBN first-pass probabilities are not yet robust across domains.
- Per-chip funnel histograms for first-pass and second-pass survival rates.
- False-negative galleries for hBN first pass and region-domain second pass.
- Detector recall audit from dense manual labels, so the deterministic proposal pass can get true recall and false-negative estimates rather than only downstream yield.

## Source Artifacts

- `outputs/candidate_baseline_20260508/candidate_baseline_summary.json`
- `outputs/candidate_good_bad_torch_20260511_run3/good_bad_torch_summary.json`
- `outputs/candidate_baseline_hbn_20260515_first_pass/candidate_baseline_summary.json`
- `outputs/first_pass_torch_hbn_20260515/first_pass_torch_summary.json`
- `outputs/candidate_good_bad_torch_hbn_20260515/good_bad_torch_summary.json`
- `outputs/candidate_good_bad_torch_hbn_20260518_combined/good_bad_torch_summary.json`
- `outputs/candidate_good_bad_torch_hbn_20260519_region_domains/good_bad_torch_summary.json`
- `outputs/candidate_good_bad_torch_hbn_20260519_region_gate_v2/good_bad_torch_summary.json`
- `photos/scans/20260514T014605Z_flake_grid_001/qc/post_scan/post_scan_summary.json`
- `photos/scans/20260515T051601Z_Isaac_BN1r2/qc/post_scan/post_scan_summary.json`
- `photos/scans/20260520T044855Z_IsaacV_AutoBN01/qc/post_scan/post_scan_summary.json`
- `outputs/autofocus_benchmark_summary.json`
- `outputs/autofocus_benchmark_top_left_failures_crop05.json`

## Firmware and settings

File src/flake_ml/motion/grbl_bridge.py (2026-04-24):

from __future__ import annotations

from dataclasses import dataclass
from pathlib import Path
import base64
import re
import subprocess


STATUS_PATTERN = re.compile(
    r"<(?P<state>[^,>]+),MPos:(?P<mx>[-\d.]+),(?P<my>[-\d.]+),(?P<mz>[-\d.]+),WPos:(?P<wx>[-\d.]+),(?P<wy>[-\d.]+),(?P<wz>[-\d.]+)>"
)
SETTING_PATTERN = re.compile(r"^\$(?P<code>\d+)=?(?P<value>[-\d.]+)?", re.MULTILINE)


@dataclass(slots=True)
class GrblStatus:
    state: str
    machine_x_mm: float
    machine_y_mm: float
    machine_z_mm: float
    work_x_mm: float
    work_y_mm: float
    work_z_mm: float
    raw: str


class PowerShellGrblBridge:
    def __init__(self, port: str, baud: int = 115200, startup_delay_ms: int = 500) -> None:
        self.port = port
        self.baud = baud
        self.startup_delay_ms = startup_delay_ms

    @staticmethod
    def _ps_quote(value: str) -> str:
        return "'" + value.replace("'", "''") + "'"

    def _build_inline_command(self, lines: list[str], wait_for: str, timeout_ms: int) -> str:
        encoded_lines = ", ".join(self._ps_quote(line) for line in lines)
        port = self._ps_quote(self.port)
        wait = self._ps_quote(wait_for)
        return (
            f"$lines = @({encoded_lines}); "
            f"$sp = New-Object System.IO.Ports.SerialPort {port},{self.baud},([System.IO.Ports.Parity]::None),8,([System.IO.Ports.StopBits]::One); "
            "$sp.ReadTimeout = 250; "
            "$sp.WriteTimeout = 1000; "
            "$sp.DtrEnable = $false; "
            "$sp.RtsEnable = $false; "
            "$sp.Open(); "
            f"Start-Sleep -Milliseconds {self.startup_delay_ms}; "
            "$flushDeadline = [DateTime]::UtcNow.AddMilliseconds(200); "
            "while([DateTime]::UtcNow -lt $flushDeadline){ $null = $sp.ReadExisting(); Start-Sleep -Milliseconds 20 }; "
            "$responses = New-Object System.Collections.Generic.List[string]; "
            "foreach($line in $lines){ "
            "if($line -eq '?'){ $sp.Write('?') } "
            "elseif($line -eq '!'){ $sp.Write('!') } "
            "elseif($line -eq '~'){ $sp.Write('~') } "
            "elseif($line -eq '__CTRL_X__'){ $sp.Write([char]24) } "
            "else { $sp.Write($line + \"`n\") }; "
            "Start-Sleep -Milliseconds 80 }; "
            f"$waitFor = {wait}; "
            f"$deadline = [DateTime]::UtcNow.AddMilliseconds({timeout_ms}); "
            "while([DateTime]::UtcNow -lt $deadline){ "
            "$chunk = $sp.ReadExisting(); "
            "if($chunk){ "
            "$responses.Add($chunk); "
            "if($waitFor -eq '__NONE__'){ break } "
            "if(($responses.ToArray() -join '').Contains($waitFor)){ break } "
            "} "
            "Start-Sleep -Milliseconds 20 "
            "}; "
            "$text = ($responses.ToArray() -join ''); "
            "$sp.Close(); "
            "Write-Output $text"
        )

    @property
    def script_path(self) -> Path:
        return Path(__file__).resolve().parents[3] / "scripts" / "grbl_send.ps1"

    def _run_script_line(self, line: str, wait_for: str, timeout_ms: int) -> str:
        command_base64 = base64.b64encode(line.encode("utf-8")).decode("ascii")
        wait_for_base64 = base64.b64encode(wait_for.encode("utf-8")).decode("ascii")
        result = subprocess.run(
            [
                "powershell.exe",
                "-NoProfile",
                "-ExecutionPolicy",
                "Bypass",
                "-File",
                str(self.script_path),
                "-Port",
                self.port,
                "-Baud",
                str(self.baud),
                "-StartupDelayMs",
                str(self.startup_delay_ms),
                "-CommandBase64",
                command_base64,
                "-WaitForBase64",
                wait_for_base64,
                "-TimeoutMs",
                str(timeout_ms),
            ],
            capture_output=True,
            text=True,
            check=False,
        )
        if result.returncode != 0:
            raise RuntimeError(result.stderr.strip() or result.stdout.strip() or "PowerShell GRBL script command failed.")
        return result.stdout.strip()

    def run_lines(self, lines: list[str], wait_for: str = "ok", timeout_ms: int = 5000) -> str:
        inline = self._build_inline_command(lines, wait_for=wait_for, timeout_ms=timeout_ms)
        result = subprocess.run(
            ["powershell.exe", "-NoProfile", "-ExecutionPolicy", "Bypass", "-Command", inline],
            capture_output=True,
            text=True,
            check=False,
        )
        if result.returncode != 0:
            raise RuntimeError(result.stderr.strip() or result.stdout.strip() or "PowerShell GRBL command failed.")
        return result.stdout.strip()

    def status(self) -> GrblStatus:
        raw = self.run_lines(["?"], wait_for="<", timeout_ms=3000)
        match = STATUS_PATTERN.search(raw)
        if not match:
            raise RuntimeError(f"Could not parse GRBL status response: {raw}")
        return GrblStatus(
            state=match.group("state"),
            machine_x_mm=float(match.group("mx")),
            machine_y_mm=float(match.group("my")),
            machine_z_mm=float(match.group("mz")),
            work_x_mm=float(match.group("wx")),
            work_y_mm=float(match.group("wy")),
            work_z_mm=float(match.group("wz")),
            raw=raw,
        )

    def unlock(self) -> str:
        return self._run_script_line("$X", wait_for="ok", timeout_ms=4000)

    def set_work_origin(self) -> str:
        return self.run_lines(["G92 X0 Y0"], wait_for="ok", timeout_ms=4000)

    def jog_relative(self, dx_um: float, dy_um: float, feed_mm_min: float) -> str:
        dx_mm = dx_um / 1000.0
        dy_mm = dy_um / 1000.0
        gcode = f"G21 G91 G0 X{dx_mm:.4f} Y{dy_mm:.4f} F{feed_mm_min:.2f}"
        return self.run_lines([gcode], wait_for="ok", timeout_ms=6000)

    def set_max_rates(self, x_mm_min: float, y_mm_min: float) -> str:
        first = self._run_script_line(f"$110={x_mm_min:.3f}", wait_for="ok", timeout_ms=4000)
        second = self._run_script_line(f"$111={y_mm_min:.3f}", wait_for="ok", timeout_ms=4000)
        return "\n".join(part for part in (first, second) if part)

    def set_acceleration(self, x_mm_s2: float, y_mm_s2: float) -> str:
        first = self._run_script_line(f"$120={x_mm_s2:.3f}", wait_for="ok", timeout_ms=4000)
        second = self._run_script_line(f"$121={y_mm_s2:.3f}", wait_for="ok", timeout_ms=4000)
        return "\n".join(part for part in (first, second) if part)

    def feed_hold(self) -> str:
        return self.run_lines(["!"], wait_for="__NONE__", timeout_ms=1000)

    def resume(self) -> str:
        return self.run_lines(["~"], wait_for="__NONE__", timeout_ms=1000)

    def soft_reset(self) -> str:
        return self.run_lines(["__CTRL_X__"], wait_for="Grbl", timeout_ms=3000)
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

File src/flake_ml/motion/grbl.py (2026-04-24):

from __future__ import annotations

from pathlib import Path
import re
import subprocess
import time

from ..models import StagePosition
from .base import MotionController


class PowerShellGrblController(MotionController):
    def __init__(
        self,
        port: str,
        baud: int = 115200,
        travel_rate_um_s: float = 2500.0,
        settle_time_ms: int = 250,
    ) -> None:
        self.port = port
        self.baud = baud
        self.travel_rate_um_s = travel_rate_um_s
        self.settle_time_ms = settle_time_ms
        self._position = StagePosition(0.0, 0.0)

    @property
    def script_path(self) -> Path:
        return Path(__file__).resolve().parents[3] / "scripts" / "grbl_send.ps1"

    def _send(self, *commands: str, wait_for: str = "ok", timeout_ms: int = 2000) -> str:
        command = [
            "powershell.exe",
            "-NoProfile",
            "-ExecutionPolicy",
            "Bypass",
            "-File",
            str(self.script_path),
            "-Port",
            self.port,
            "-Baud",
            str(self.baud),
            "-TimeoutMs",
            str(timeout_ms),
            "-WaitFor",
            wait_for,
        ]
        for line in commands:
            command.extend(["-Command", line])
        result = subprocess.run(command, capture_output=True, text=True, check=False)
        if result.returncode != 0:
            raise RuntimeError(result.stderr.strip() or "Failed to communicate with GRBL.")
        return result.stdout.strip()

    def unlock(self) -> str:
        return self._send("$X")

    def home(self) -> None:
        self._send("$H", wait_for="ok", timeout_ms=10000)
        self._position = StagePosition(0.0, 0.0)

    def move_abs(self, x_um: float, y_um: float) -> None:
        x_mm = x_um / 1000.0
        y_mm = y_um / 1000.0
        feed_mm_min = max((self.travel_rate_um_s * 60.0) / 1000.0, 0.1)
        self._send("G21", "G90", f"G1 X{x_mm:.4f} Y{y_mm:.4f} F{feed_mm_min:.2f}")
        self._position = StagePosition(float(x_um), float(y_um))
        self.wait_for_idle()

    def move_rel(self, dx_um: float, dy_um: float) -> None:
        new_x = self._position.x_um + dx_um
        new_y = self._position.y_um + dy_um
        self.move_abs(new_x, new_y)

    def status(self) -> str:
        return self._send("?", wait_for="<", timeout_ms=1500)

    def wait_for_idle(self) -> None:
        deadline = time.time() + 20.0
        while time.time() < deadline:
            response = self.status()
            if "Idle" in response:
                time.sleep(self.settle_time_ms / 1000.0)
                return
            time.sleep(0.1)
        raise TimeoutError("GRBL did not return to Idle before timeout.")

    def current_position(self) -> StagePosition:
        response = self.status()
        match = re.search(r"MPos:([-\d.]+),([-\d.]+)", response)
        if match:
            return StagePosition(float(match.group(1)) * 1000.0, float(match.group(2)) * 1000.0)
        return self._position

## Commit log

2026-04-14 Correct microscope references to Zeiss Axio
    [Microscope_Scan.stl, focus_conical_clamp_pulley.scad, focus_conical_clamp_pulley_left_half.step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]
2026-04-15 Add curated donor CAD workspace for Zeiss Axio retrofit
    [00_XYTable_large_gear.ipt, 00_XYTable_medium_gear.ipt, 00_XYTable_pulley.ipt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]
2026-04-15 Add freestanding Zeiss Axio XY-only stage project
    [Assembly_XYTable_Aliepexress_00_XYTable_large_gear_29.stl, Assembly_XYTable_Aliepexress_00_XYTable_medium_gear_27.stl, Assembly_XYTable_Aliepexress_00_XYTable_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]
2026-04-15 Upgrade XY pulleys to compliant anti-slip clamp design
    [axio_x_knob_pulley_left_half.stl, axio_x_knob_pulley_liner_left_half.stl, axio_x_knob_pulley_liner_right_half.stl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]
2026-04-15 Clarify XY pod slots and add cable routing features
    [x_drive_preview_motor_plate.stl, xy_pod_motor_plate_nema17.stl, y_drive_preview_motor_plate.stl]
2026-04-15 Simplify XY pulleys to rigid halves with cut liner
    [axio_x_knob_pulley_left_half.stl, axio_x_knob_pulley_liner_left_half.stl, axio_x_knob_pulley_liner_right_half.stl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]
2026-04-18 Add Arduino XY jog sketch
2026-04-18 Add GRBL bring-up guide
2026-04-22 Replace repo contents with FlakeID bootstrap stack
    [00_XYTable_large_gear.ipt, 00_XYTable_medium_gear.ipt, 00_XYTable_pulley.ipt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]
2026-04-22 Add safe stage-bounds protocol and planner limits
2026-04-22 Add stage calibration UI for bounds and motion tuning
2026-04-23 Use native Windows stage calibration UI launcher
2026-04-23 Use G1 feed-controlled motion for stage moves
2026-04-24 Add camera workflow and drift correction tooling
